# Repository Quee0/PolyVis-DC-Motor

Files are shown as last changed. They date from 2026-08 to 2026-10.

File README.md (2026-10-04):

# PolyVis DC Motor ⚡️

<p align="left">
  
  
  
</p>

<p align="center">
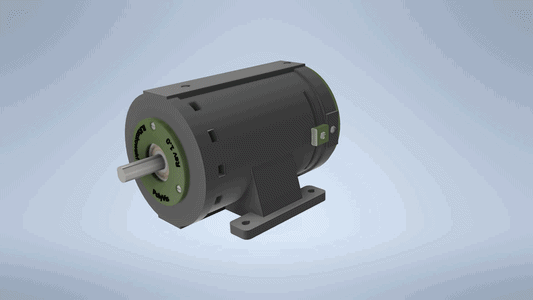
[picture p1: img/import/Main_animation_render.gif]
Podpis alternatywny
  
</p>

## 1. Project Overview

### 1.1 General Description

PolyVis is a fully functional, hybrid (3D-printed plastic + solid steel) brushed DC motor designed from scratch. The main goal was to create viable DC Motor, that can be built without expensive tools and hard-to-source materials. Furthermore its development was an R&D process bringing theoretical electromagnetism, Finite Element Analysis (FEA), and practical DIY manufacturing.

> [!NOTE]
> **This includes:**
>
> * Automated FEA methodology utilizing custom Python and Lua scripts for geometry generation and simulation,
> * Advanced parameters calculations using the Maxwell Stress Tensor to evaluate both electrodynamic and reluctance forces,
> * Real world characteristics reaserch,
> * Two-layer simplex lap winding integrated with a 6-segment commutator for smooth current switching,
> * Hybrid material architecture bridging the gap between accessible 3D printing and necessary ferromagnetic properties.

The end result is a fully functional prototype capable of validating theoretical models in the real world, demonstrating a practical understanding of electromagnetic design and applied physics.

### 1.2 Project & Idea Evolution

Initial assumptions involved building a brushed motor using easily available materials (3D printing, off-the-shelf parts). Method of estimating parameters, and whole project concept underwent a drastic and necessary transformation.

### 1.2.1 Material selection

#### ❌ All-Plastic Construction:

The original idea relied on 3D printing entire motor (except for the windings and magnets). It is quite common approch in DIY projects that demonstrates the working mechanism of brushed DC motor (or BLDC). This design was abandoned.

> [!NOTE]
> Plastic has a magnetic permeability close to that of a vacuum ( $\mu \approx \mu_0$ ). The lack of a ferromagnetic material in the magnetic circuit makes concentrating the magnetic flux impossible, which in practice means drastically low efficiency and negligible torque.

#### ✅ Hybrid Construction (Plastic + Solid Steel):

To solve the lack of a ferromagnetics, the concept evolved into a hybrid solution. The rotor would be a plastic skeleton with an embedded steel core, and the stator is based on a solid steel pipe. To generate a strong 2-pole field using standard components, a multi-segment architecture was adopted. One half of the inner circumference is lined with small magnets facing with their N pole, and the other half with their S pole.

> [!NOTE]
> Solid steel is exposed to eddy currents, which would melt whole construction. Because this engine would be limited by its hybrid approch, the change of magnetic field in stator (eddy currents) would be negligible. On the other hand, rotor must be laminated. This hybrid was a conscious compromise. The lower efficiency and losses of this construction were accepted. This is a trade-off allows for the fabrication of a prototype in a home workshop environment.

### 1.2.2 Evolution of the Computational Methodology

Determining the forces and torque required the creation of a reliable mathematical model. This model went through successive stages, discarding simplified assumptions in favor of a full electromagnetic simulation.

**1. Custom Python Script:**

* **Idea:** Custom simulation script of dipole distribution in a vacuum. The tool had immense educational value and developed physical intuition, but the script could not model the ferromagnetic material behaviour.
* **Verdict:** This solution was rejected as the primary design tool. Nonetheless this project is a great educational tool and an enormous help for visualising magnetic field in free space. Mathematics was derived and developed based on equations "Introduction to Electrodynamics" by David J. Griffiths - a foundational text in the field.
  *Note: The code was spun off into a standalone repository:* [`dipole-magnetostatic-solver`](https://github.com/Quee0/dipole-magnetostatic-solver).

**2. Classical Magnetic Circuit (Reluctance modeling):**

* **Idea:** Another approch to this problem was to solve a magnetic circuit. This method quickly ran into a problem with calculating reluctances of airgaps.
* **Verdict:** After reaserch, finding equations for different reluctances shapes and mailing a professor from my university suggested that this method cannot be precise. It failed due to a lack of reliable empirical data for the complex geometry.

#### Finite element analysis (FEMM & Lorentz Force):

* **Idea:** To be as precise as possible in this kind of project FEA method was chosen (via free FEMM software). Initial thought was to simulate wide range of geometries and then integrate forces acting solely on current-carrying conductors placed in the slots.
* **Verdict:** This method is used in standard electrodynamics courses, but it does not consider reluctance forces (lorenz force on ferromagnetics carrying the current). Upon further reaserch I choose to stick to FEMM software and develop results based on Maxwell stress tensor.

#### Final Model (FEA FEMM & Maxwell Stress Tensor):

* **Idea:** Utilizing the FEA environment (FEMM) to simulate the field distribution with full consideration of material non-linearities. Torque is determined directly using the Maxwell Stress Tensor.
* **Verdict:** Integrating stresses over a virtual contour (volume) surrounding the rotor allows for precise inclusion of both electrodynamic and reluctance forces in a single pass. It calculates forces based on fields nonsymmetry caused by the rotor. Theoretical derivation is in math chapter. In parallel with the magnetic verification, key electrical and topological parameters were established, forming the foundation for the commutator's construction:Topology: Simplex lap winding.

## 2. Simulation, Calculations & Geometry Selection

<p align="center">
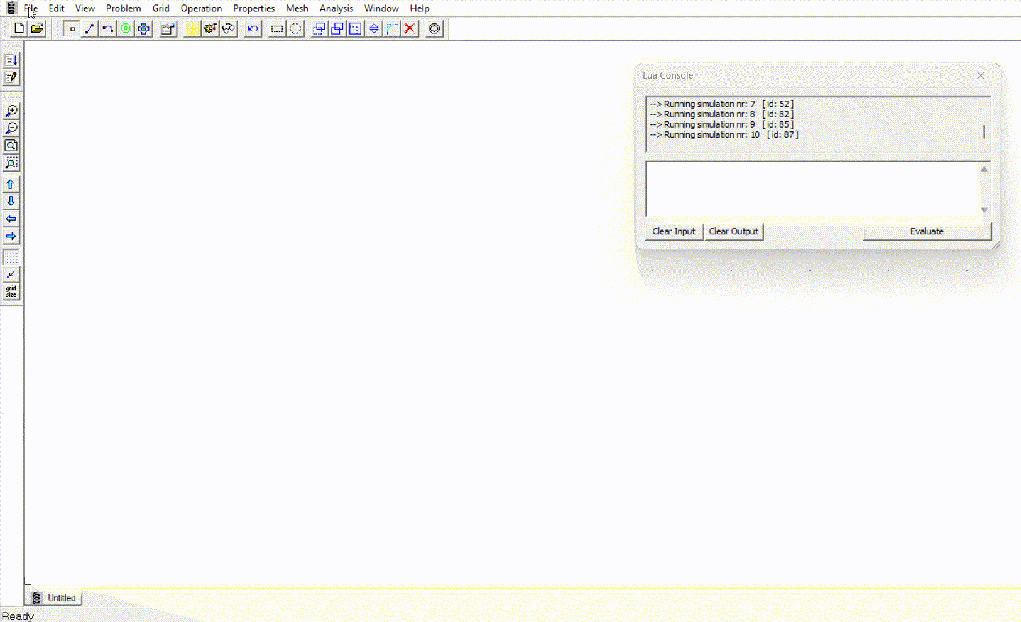
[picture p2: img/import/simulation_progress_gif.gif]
  
</p>

The current script model for geometry optimization and selection was developed on the open-source finite element analysis tool - FEMM (`www.femm.info`). The script generates and tests various geometries, then simulates them and writes the data to Excel. On this basis, it was possible to select the target geometry and manually correct the parameters.

### 2.1 Simulation Files

```
root-directory
├── ...
└── simulation_femm/
    ├── femm_handler_2nd_iteration.py
    ├── femm_handler.py
    ├── geometry_setup.lua
    └── output.csv
```

**2nd iteration arised after aknowleding parameter problems in the first one. You can change parameters in either of them.**

### 2.2 Running the Simulation

The simulation process has been fully automated using Python and Lua scripts. Python generates geometries and later opens FEMM with lua scripting. To run this script, you need to set up the appropriate working environment.

* **Install Python** (version 3.x).
* **Install FEMM 4.2** (Finite Element Method Magnetics).

> [!WARNING]
> **Critical path requirement:** The main Python script calls the simulation engine directly. During the FEMM installation, make sure the destination path is exactly (or change destination in script):
> `C:\femm42\bin\femm.exe`

The script utilizes external libraries for data handling and generating final result spreadsheets. Install them using the `pip` package manager:

```bash
pip install numpy pandas xlsxwriter
```

To begin the Monte Carlo simulation, open a terminal in the target folder and run the script:

```bash
python femm_handler_2nd_iteration.py
```

**Background execution process:**
Upon launch, the script will automatically generate the `femm_input.lua` parameter batch file and execute the FEMM engine. Each valid geometry will be simulated and temporarily saved to the `output.csv` file. Once all iterations are complete, the script will sort the data by the highest torque and export a clean spreadsheet named `Simulation_output.xlsx`.

### 2.3 Maxwell stress tensor derivation

Main calculation done directly in FEMM is torque on rotor. I used volumetric integral (surface integral in 2D) of Maxwell's stress tensor. Typical academical approach to electromagnetic problems is to treat them as tranciver and reciver. One object generates electromagnetic field and the other expirience force. Based on my reaserch this approach is insufficient. It cannot easily determine forces on ferromagnetic elements (reluctance forces). Alternative approach is derived based on assimetry of electromagnetic field. It evaluates both the electrodynamic forces acting on the coils and the reluctance forces exerted on the ferromagnetic components. While the Virtual Work method provides a viable alternative for capturing reluctance forces through magnetic energy variations, the Maxwell stress tensor was selected for its direct and computationally efficient integration along the bounding surface.

#### Stress tensor derivation:

<details>
<summary><b> Expand for further details </b></summary>

Total electromagnetic force:

$$\mathbf{F} = q(\mathbf{E} + \mathbf{v} \times \mathbf{B}) = \int\int\int (\mathbf{E} + \mathbf{v} \times \mathbf{B})\rho dV$$

The force per unit volume is:

$$\mathbf{f} = \rho\mathbf{E} + \mathbf{J} \times \mathbf{B}$$

Next, charge density $\rho$ and current density $\mathbf{J}$ can be expressed in terms of fields $\mathbf{E}$ and $\mathbf{B}$, using Gauss's law and Ampère's law:

$$\mathbf{f} = \varepsilon_0 (\nabla \cdot \mathbf{E}) \mathbf{E} + \frac{1}{\mu_0} (\nabla \times \mathbf{B}) \times \mathbf{B} - \varepsilon_0 \frac{\partial \mathbf{E}}{\partial t} \times \mathbf{B}$$

Another transformation comes from rewriting the Poynting vector. Using the product rule and Faraday's law of gives:

$$\frac{\partial}{\partial t} (\mathbf{E} \times \mathbf{B}) = \frac{\partial \mathbf{E}}{\partial t} \times \mathbf{B} + \mathbf{E} \times \frac{\partial \mathbf{B}}{\partial t} = \frac{\partial \mathbf{E}}{\partial t} \times \mathbf{B} - \mathbf{E} \times (\nabla \times \mathbf{E})$$

And now $\mathbf{f}$ as:

$$\mathbf{f} = \varepsilon_0 (\nabla \cdot \mathbf{E}) \mathbf{E} + \frac{1}{\mu_0} (\nabla \times \mathbf{B}) \times \mathbf{B} - \varepsilon_0 \frac{\partial}{\partial t} (\mathbf{E} \times \mathbf{B}) - \varepsilon_0 \mathbf{E} \times (\nabla \times \mathbf{E})$$

Rearrange $\mathbf{E}$ and $\mathbf{B}$:

$$\mathbf{f} = \varepsilon_0 \left[ (\nabla \cdot \mathbf{E}) \mathbf{E} - \mathbf{E} \times (\nabla \times \mathbf{E}) \right] + \frac{1}{\mu_0} \left[ -\mathbf{B} \times (\nabla \times \mathbf{B}) \right] - \varepsilon_0 \frac{\partial}{\partial t} (\mathbf{E} \times \mathbf{B})$$

"Fixing" symmetry by inserting $0 = (\nabla \cdot \mathbf{B}) \mathbf{B}$:

$$\mathbf{f} = \varepsilon_0 \left[ (\nabla \cdot \mathbf{E}) \mathbf{E} - \mathbf{E} \times (\nabla \times \mathbf{E}) \right] + \frac{1}{\mu_0} \left[ (\nabla \cdot \mathbf{B}) \mathbf{B} - \mathbf{B} \times (\nabla \times \mathbf{B}) \right] - \varepsilon_0 \frac{\partial}{\partial t} (\mathbf{E} \times \mathbf{B})$$

Eliminating the crossproducts (which are complicated to calculate), using the vector calculus identity:

$$\frac{1}{2} \nabla (\mathbf{A} \cdot \mathbf{A}) = \mathbf{A} \times (\nabla \times \mathbf{A}) + (\mathbf{A} \cdot \nabla) \mathbf{A} ,$$

leads to:

$$\mathbf{f} = \varepsilon_0 \left[ (\nabla \cdot \mathbf{E}) \mathbf{E} + (\mathbf{E} \cdot \nabla) \mathbf{E} \right] + \frac{1}{\mu_0} \left[ (\nabla \cdot \mathbf{B}) \mathbf{B} + (\mathbf{B} \cdot \nabla) \mathbf{B} \right] - \frac{1}{2} \nabla \left( \varepsilon_0 E^2 + \frac{1}{\mu_0} B^2 \right) - \varepsilon_0 \frac{\partial}{\partial t} (\mathbf{E} \times \mathbf{B}) .$$

This expression contains every aspect of electromagnetism and momentum and is relatively easy to compute. It can be written more compactly by introducing the **Maxwell stress tensor**,

$$\sigma_{ij} = \varepsilon_0 \left( E_i E_j - \frac{1}{2} \delta_{ij} E^2 \right) + \frac{1}{\mu_0} \left( B_i B_j - \frac{1}{2} \delta_{ij} B^2 \right) .$$

All but the last term of $\mathbf{f}$ can be written as the tensor divergence of the Maxwell stress tensor, giving:

$$\nabla \cdot \boldsymbol{\sigma} = \mathbf{f} + \varepsilon_0 \mu_0 \frac{\partial \mathbf{S}}{\partial t} ,$$

In FEMM we analise magnetostatic problem, so time derivative of Poynting vector is always 0, so:

$$\mathbf{f} = \nabla \cdot \boldsymbol{\sigma},$$

We integrate force per unit volume to get total force enduced on volume:

$$F = \int\int\int \mathbf{f} dV = \int\int\int \nabla \cdot \boldsymbol{\sigma} dV,$$

And finally we use the divergance theorem to get rid of nabla and replace integral type:

$$F = \int\int \boldsymbol{\sigma} \cdot dS$$

(Complete derivation: https://en.wikipedia.org/wiki/Maxwell_stress_tensor)

</details>

### 2.4 Motor parameters calculation model

<p align="center">
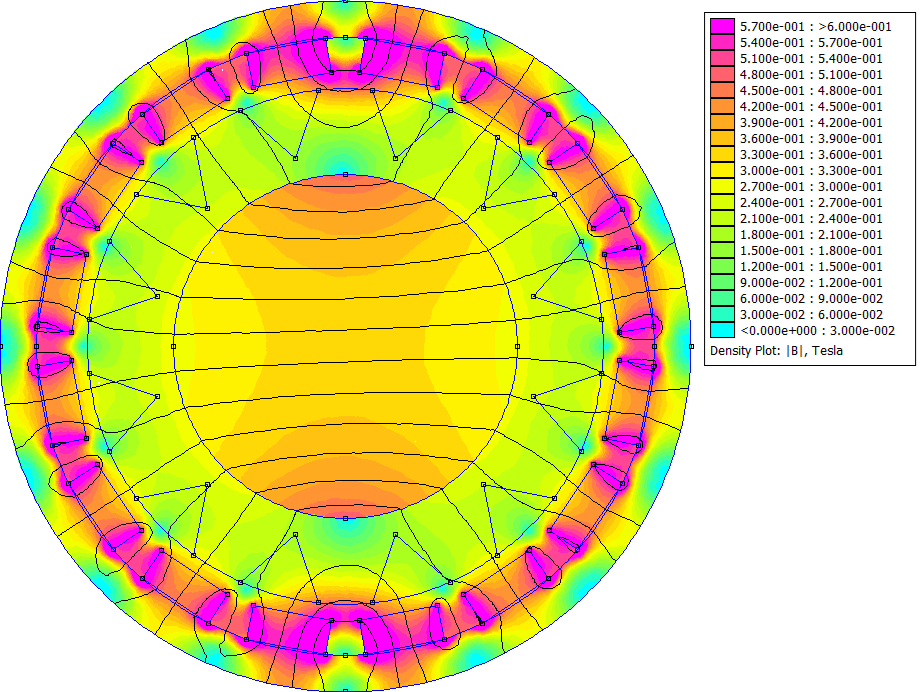
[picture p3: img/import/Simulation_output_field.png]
  
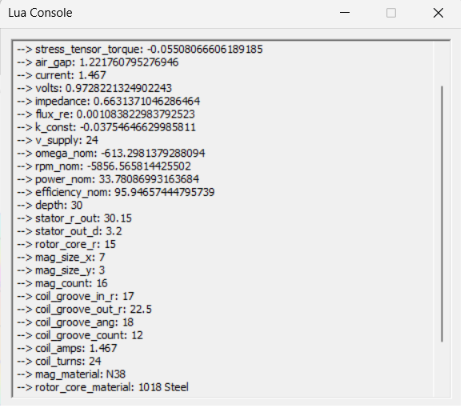
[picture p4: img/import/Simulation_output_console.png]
  
</p>

Apart from defined and read parameters, python & lua scripts calculate and evaluate more expected values.

* **Torque Constant ($k_{const}$):** Determined as total electromagnetic torque (calculated using the Maxwell Stress Tensor) devided by the current flowing through the winding.

$$k_{const} = \frac{T}{I}$$

* **Back EMF:** The script calculates the voltage drop across the windings, incorporating a correction factor of $1.45$. The electromotive force is the difference between the defined supply voltage ($V_{supply} = 24\text{ V}$) and this voltage drop.

$$EMF = V_{supply} - (I \cdot Z)$$

* **Rotational Speed ($\omega$):** The angular velocity ($\omega$) in radians per second is the Back-EMF devided by the torque constant.

$$\omega = \frac{EMF}{k_{const}}$$

It can be later recalculated into RPM:

$$RPM = \omega \cdot \frac{30}{\pi}$$

* **Energy Efficiency ($\eta$):** Defined as the ratio of useful mechanical power to the total electrical power consumed. In non ideal reality efficienty is lower, because of work done by resistance forces. Despite that, this calculation allowed to compare different geometries.

$$\eta = \frac{\omega \cdot T}{V_{supply} \cdot I} \cdot 100\%$$

---

<details>
<summary><b> Verification of the output parameters: </b></summary>

* Electromagnetic torque ($T$): $-0.055\text{ Nm}$
* Current ($I$): $1.47\text{ A}$
* Voltage drop ($V_{drop}$): $0.973\text{ V}$
* Supply voltage ($V_{supply}$): $24\text{ V}$
* **Torque constant ($k_t$):**

$$k_const = \frac{-0.055}{1.467} = -0.0375$$

* **Nominal angular velocity ($\omega$):**

$$\omega = \frac{24 - 0.973}{-0.0375} = -613.3 \text{ rad/s}$$

* **Rotational speed (RPM):**

$$RPM = -613.3 \cdot \frac{30}{\pi} = -5856.6$$

* **Useful mechanical power ($P_{mech}$):**

$$P_{mech} = -613.3 \cdot (-0.055) = 33.8 \text{ W}$$

* **Total efficiency ($\eta$):**

$$\eta = \frac{33.8}{24 \cdot 1.467} \cdot 100 = 95.95 \%$$

</details>

### 2.5 Winding schamatic

This construction utilizes a two-layer simplex lap winding. It is integrated with a 12-slot core and a 6-segment commutator. The winding process begins at `Plate 1` which, at the illustrated commutation moment, serves as the positive voltage application point. The wire forms the first coil (L1) spanning from slot 1 to 7, and then directly proceeds to form the second coil (L2) routed through slots 2 to 8. This dual series sequence terminates at `Plate 2`. This configuration is replicated symmetrically around the entire commutator. The topology completes its loop by physically connecting the output of the final coil L12 (12-6) back to the initial `Plate 1`. After `Plate 4`, coils are wound as a second layer. It allows for the utilization of all plates while maintaining one-way current flow within each slot. Positioning the opposite power terminal (GND) on `Plate 4` effectively divides this closed circuit into two symmetrical, parallel current branches.

<p align="center">
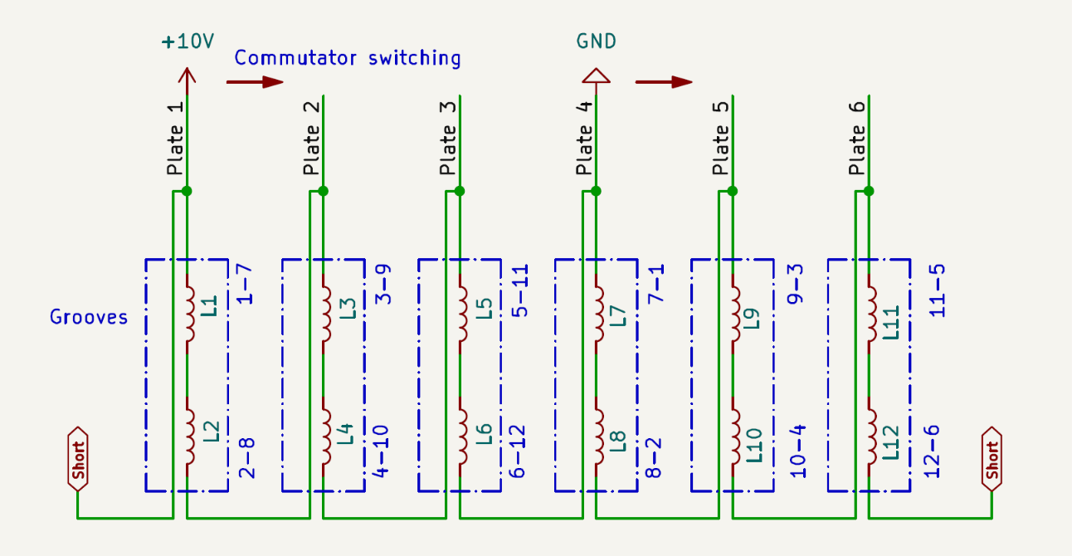
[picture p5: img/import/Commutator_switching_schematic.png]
  
</p>

## 3. Physical Build

### 3.X Motor Performance Characteristics

To fully validate the physical build motor, its real-world performance is mapped against standard brushed DC motor characteristic curves. These idealized curves illustrate how the machine's primary parameters behave as the mechanical load (Torque) on the shaft increases from a free-spinning state (No-Load) to a complete stop (Stall).

<p align="center">
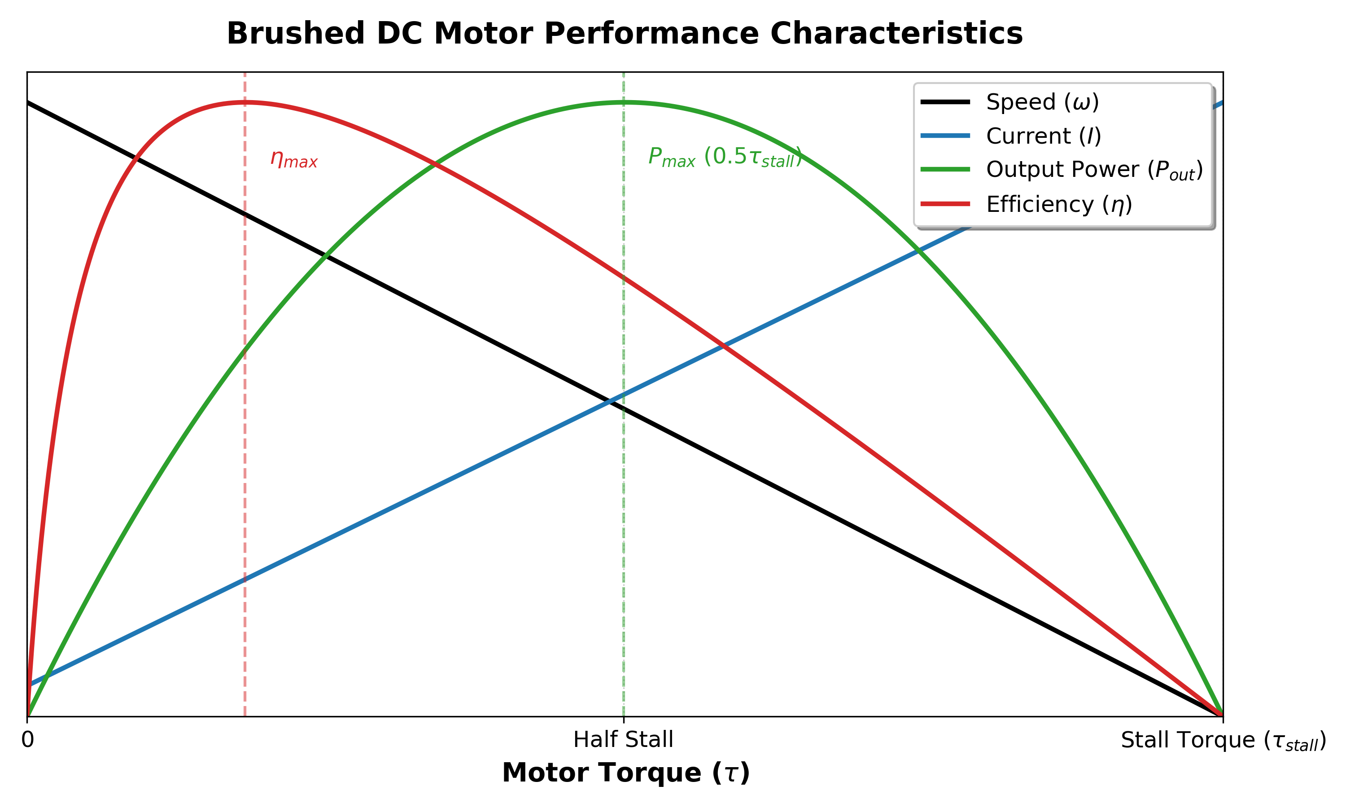
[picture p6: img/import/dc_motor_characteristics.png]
  
</p>

* **Rotational Speed ($\omega$):** Exhibits a linear decline as torque increases. The motor operates at its highest velocity under no load ($n_0$) and linearly drops to zero when the load exceeds the motor's capacity (Stall Torque).
* **Current Draw ($I$):** Shows a direct, linear increase proportional to the applied torque. It begins at a minimal no-load current (the energy required to overcome internal mechanical friction and magnetic losses) and reaches its absolute peak at stall condition.
* **Mechanical Output Power ($P_{out}$):** Forms a classic parabolic curve. Since mechanical power is the product of angular speed and torque ($P = \omega \cdot \tau$), it equals zero at both extremes (no torque and no speed). The maximum output power ($P_{2max}$) is theoretically achieved exactly at 50% of the stall torque and 50% of the no-load speed.
* **Efficiency ($\eta$):** Represents the ratio of useful mechanical power output to the electrical power input. The efficiency rises sharply to its maximum peak ($\eta_{max}$) at relatively low torque values (typically around 10-20% of the stall torque, often denoted as roughly $1/7 M_h$). Beyond this optimal point, as current (and resistive $I^2R$ heating) increases drastically, efficiency gradually drops to zero at the stall point.

## 4. CAD

## 5. Bill of materials

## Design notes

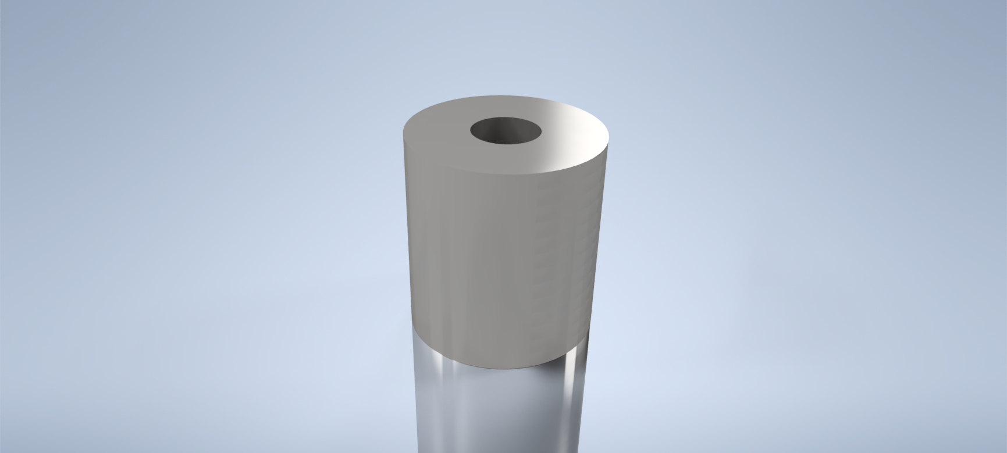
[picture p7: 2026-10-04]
model/renders/rotor_core.png

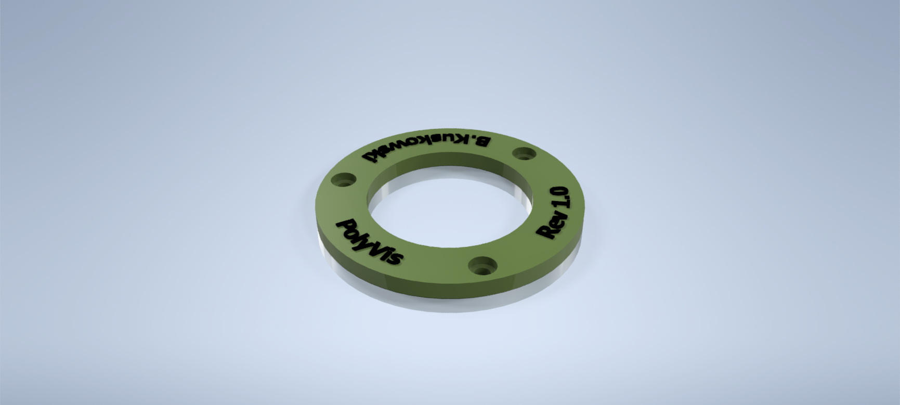
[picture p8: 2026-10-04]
model/renders/name_plate.png

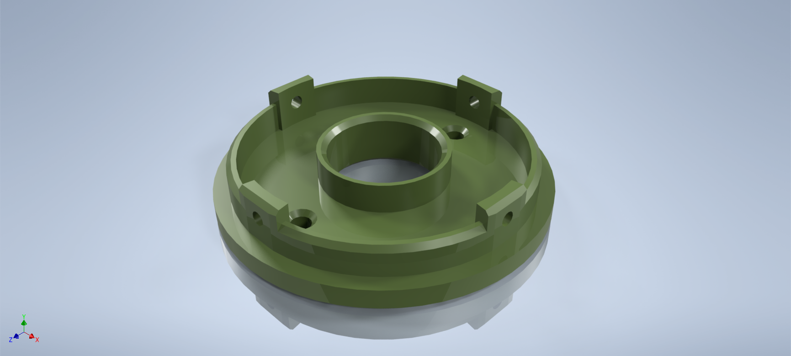
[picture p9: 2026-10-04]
model/renders/back_sleeve.png

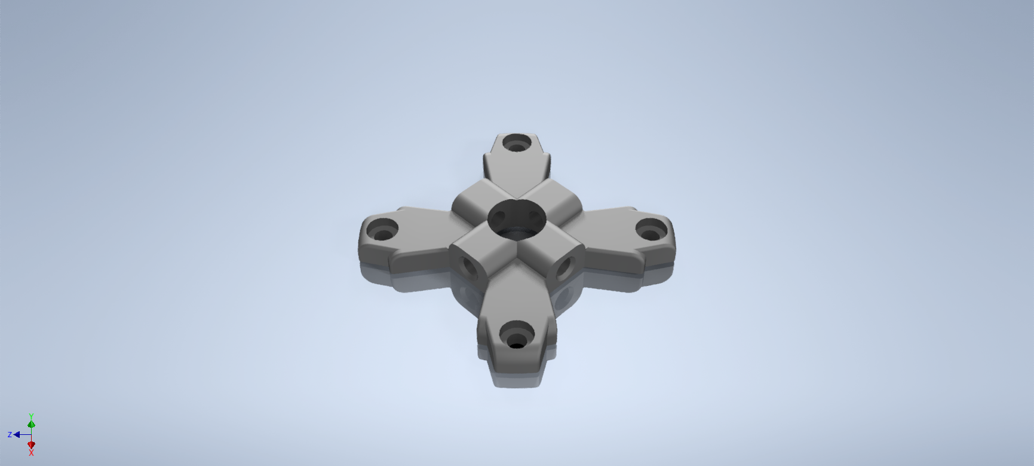
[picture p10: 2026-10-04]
model/renders/shaft_lock.png

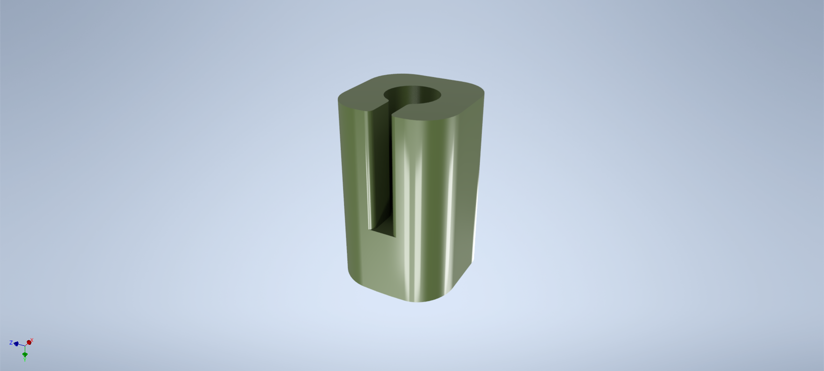
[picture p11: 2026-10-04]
model/renders/brush_holder_batt.png

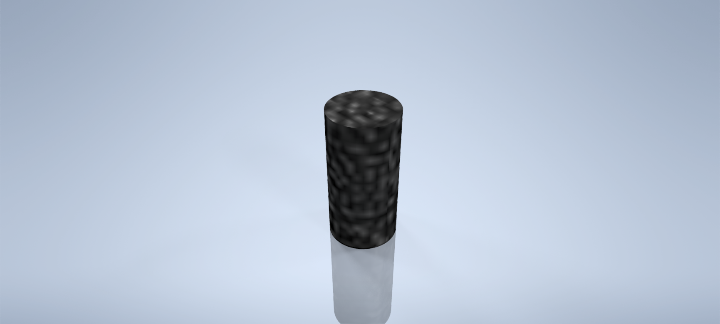
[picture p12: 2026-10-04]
model/renders/carbon_brush_batt.png

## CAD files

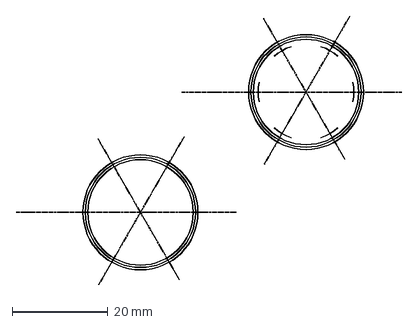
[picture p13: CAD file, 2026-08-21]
model/parts/commutator_plate_cut.dxf
80.4 x 56.0 mm

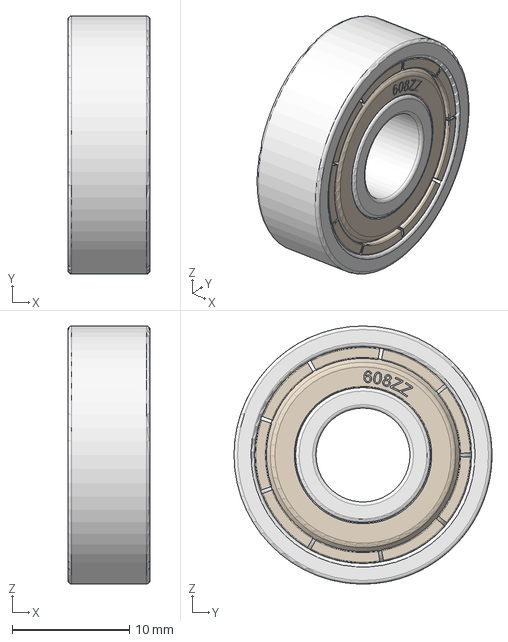
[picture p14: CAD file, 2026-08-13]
model/parts/import/608zz.step
7.00 x 22.0 x 22.0 mm

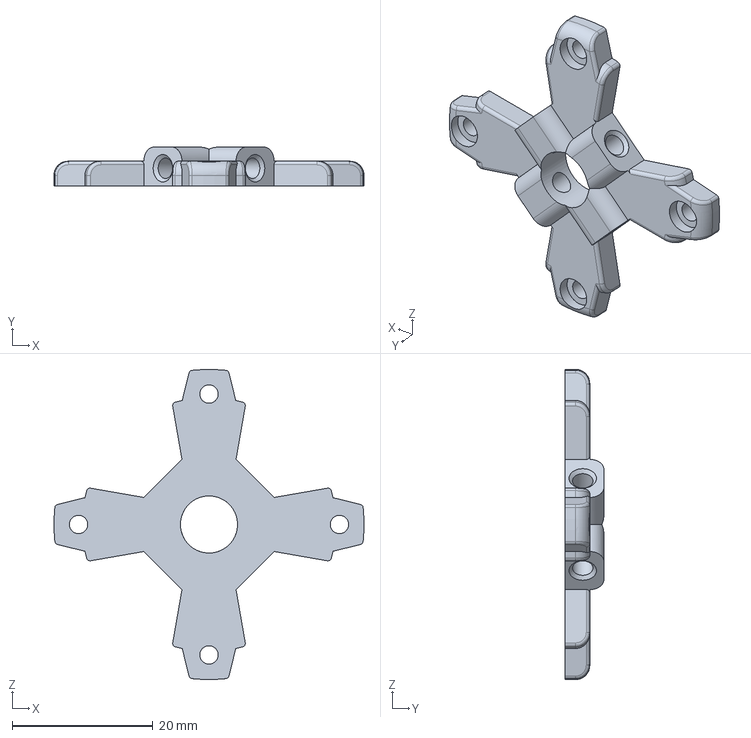
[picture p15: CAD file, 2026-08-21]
model/prints/shaft_lock_1.stp
44.0 x 5.50 x 44.0 mm

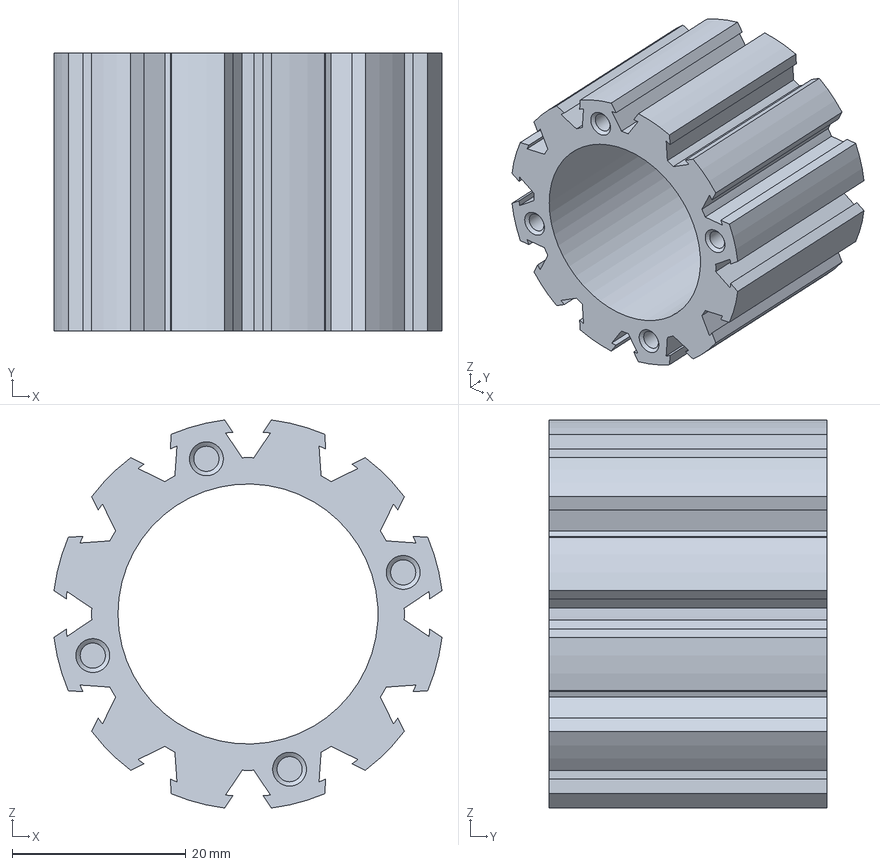
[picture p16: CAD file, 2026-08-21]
model/prints/rotor_plastic.stp
44.7 x 32.0 x 44.7 mm

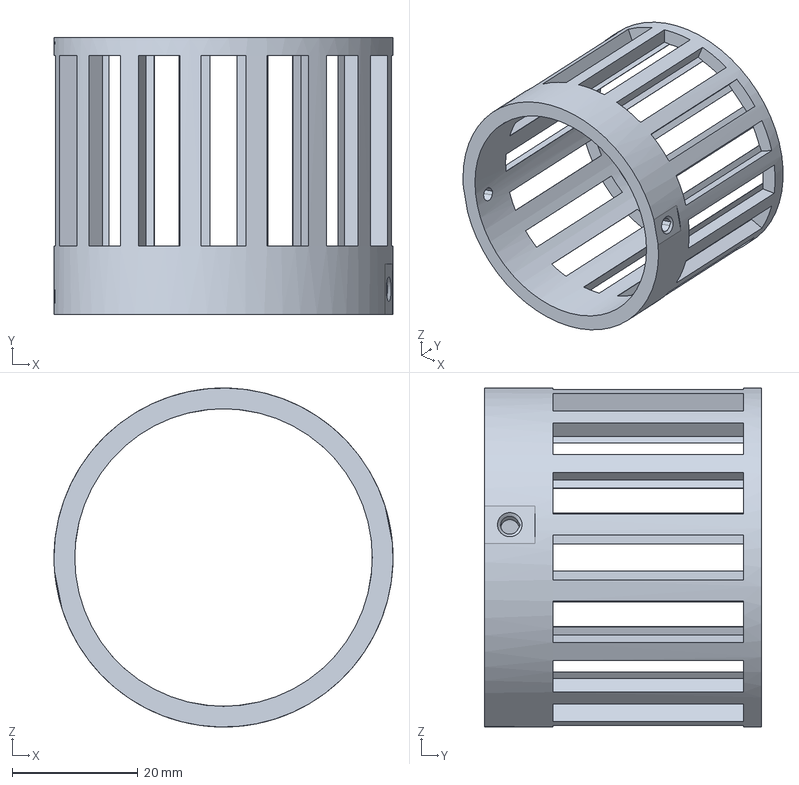
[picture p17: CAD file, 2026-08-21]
model/prints/magnet_ring.stp
53.9 x 44.0 x 53.9 mm

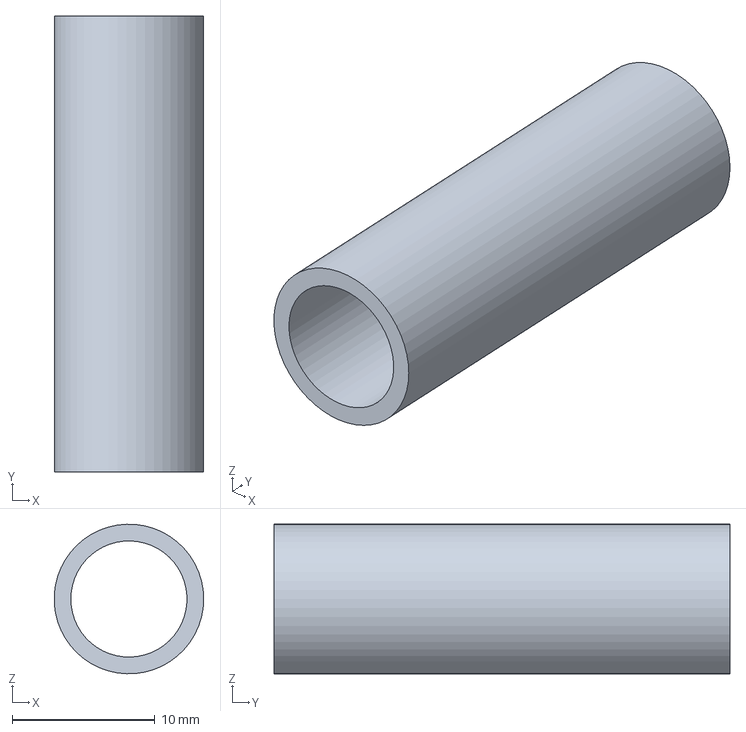
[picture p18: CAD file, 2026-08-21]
model/prints/rotor_sleeve.stp
10.5 x 32.0 x 10.5 mm

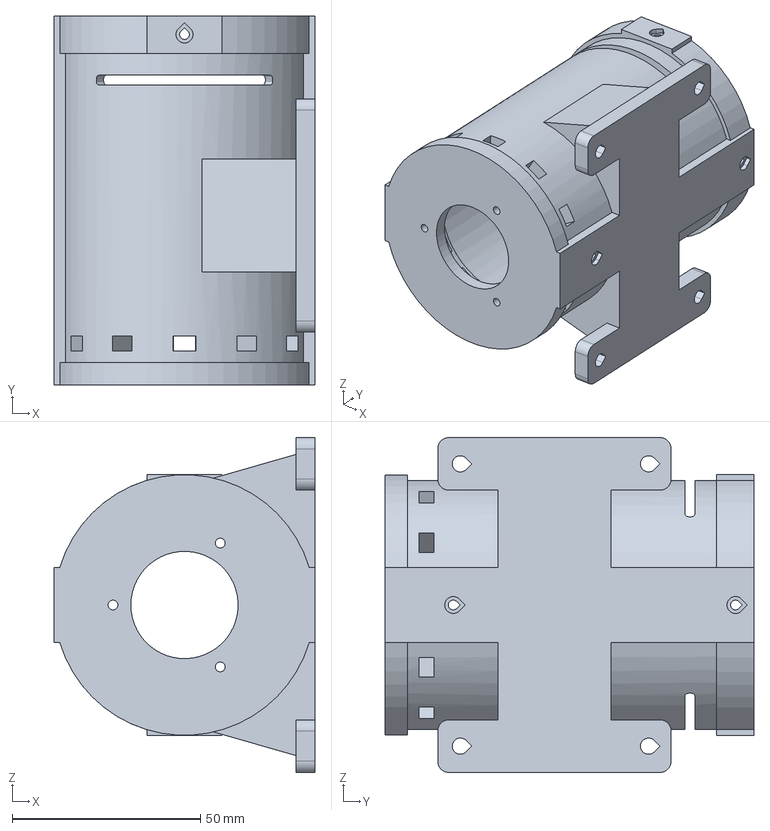
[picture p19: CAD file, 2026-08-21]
model/prints/casing_cylindrical.stp
69.2 x 98.0 x 89.0 mm

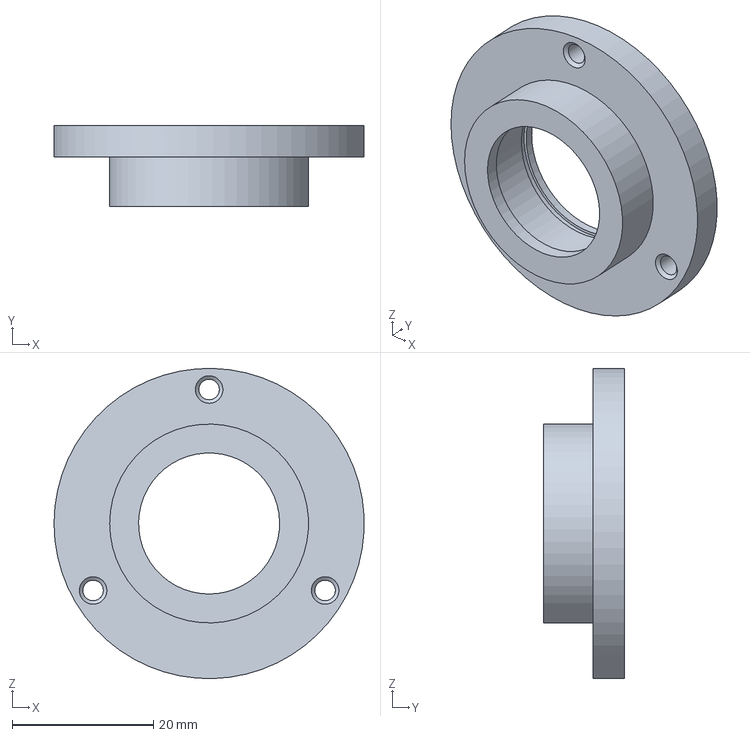
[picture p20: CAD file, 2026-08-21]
model/prints/sleeve.stp
44.0 x 11.5 x 44.0 mm

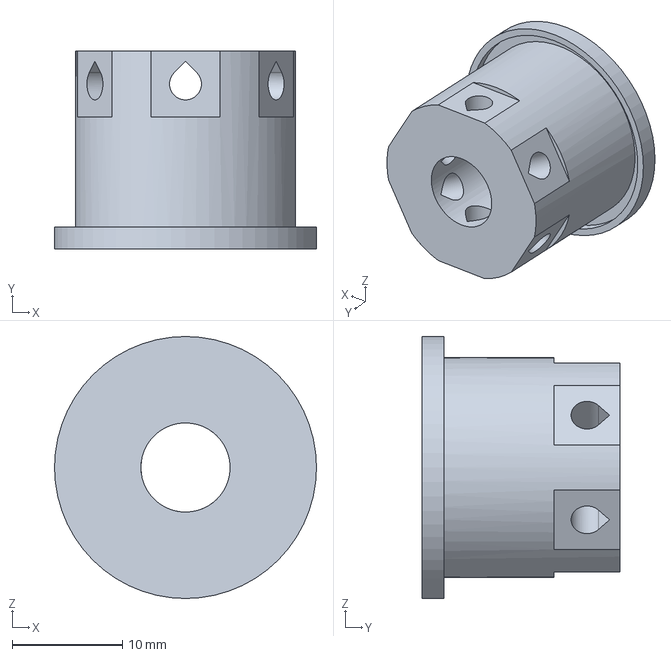
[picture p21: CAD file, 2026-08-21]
model/prints/commutator_plastic.stp
23.8 x 18.0 x 23.8 mm

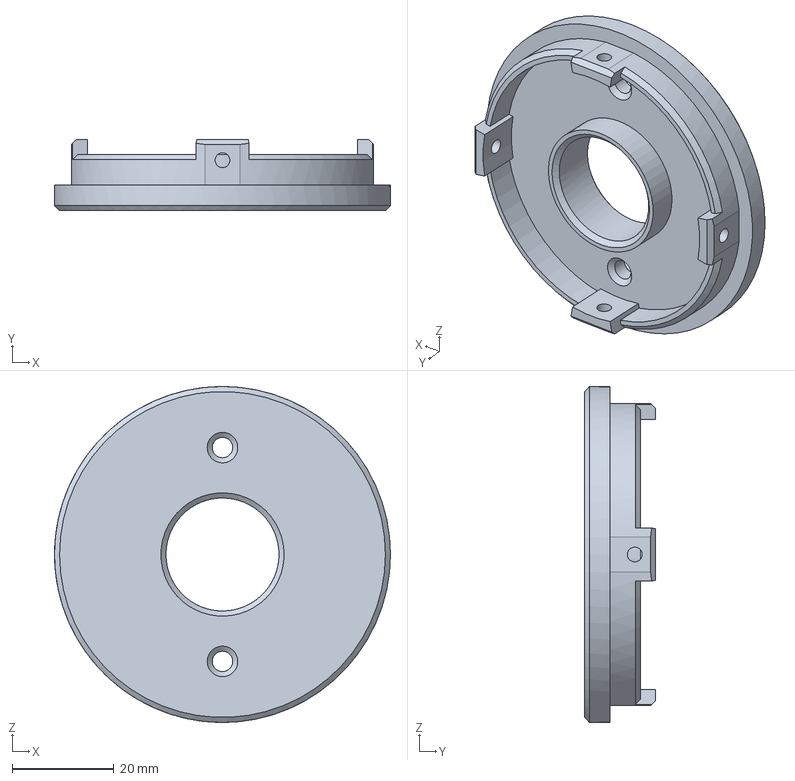
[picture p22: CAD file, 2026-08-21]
model/prints/back_sleeve.stp
66.0 x 14.0 x 66.0 mm

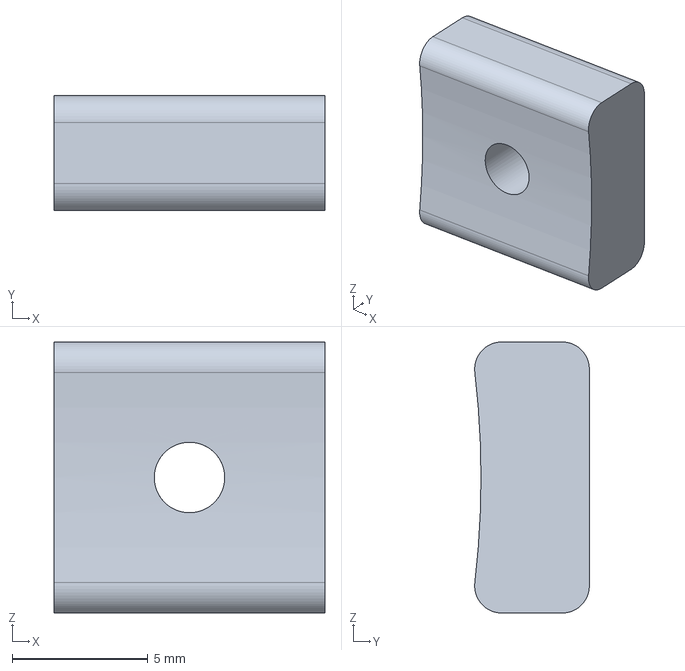
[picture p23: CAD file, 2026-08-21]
model/prints/brush_cart_outer_holder.stp
10.0 x 4.24 x 10.0 mm

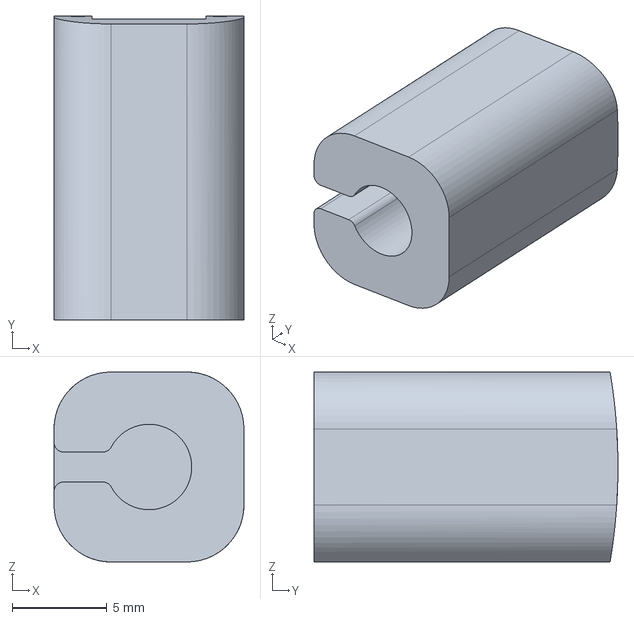
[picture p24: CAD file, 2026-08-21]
model/prints/brush_holder_batt.stp
10.0 x 16.0 x 10.0 mm

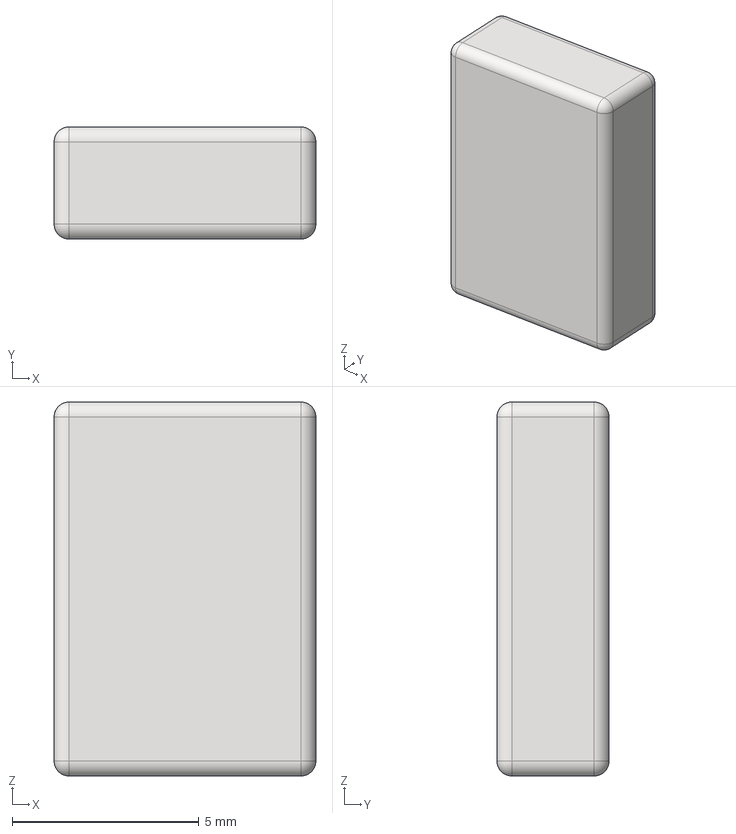
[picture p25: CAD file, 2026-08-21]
model/prints/stator_magnet_tester.stp
7.00 x 3.00 x 10.0 mm

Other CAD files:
model/prints/template.3mf
model/prints/shaft_lock_2.stp
model/assemblies/commutator_assembly.iam
model/assemblies/magnet_ring_assembly.iam
model/assemblies/main_assembly.iam
model/assemblies/main_assembly_presentation.ipn
model/assemblies/rotor_core.iam
model/parts/608zz.ipt
model/parts/back_sleeve.ipt
model/parts/brush_cart_outer_holder.ipt
model/parts/brush_cart_outer_holder_MIR.ipt
model/parts/brush_holder_batt.ipt
model/parts/brush_holder_batt_MIR.ipt
model/parts/brush_spring.ipt
model/parts/carbon_brush_batt.ipt
model/parts/carbon_brush_batt_MIR.ipt
model/parts/casing_cylindrical.ipt
model/parts/commutator_plastic.ipt
model/parts/commutator_plate.ipt
model/parts/magnet_ring.ipt
model/parts/name_plate.ipt
model/parts/rotor_plastic.ipt
model/parts/rotor_sleeve.ipt
model/parts/shaft.ipt
model/parts/shaft_lock_1.ipt
model/parts/shaft_lock_2.ipt
model/parts/single_coil.ipt
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

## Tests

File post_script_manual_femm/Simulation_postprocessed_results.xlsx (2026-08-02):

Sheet: Results
session_id | stress_tensor_torque | air_gap | current | volts | impedance | flux_re | k_const | v_supply | omega_nom | rpm_nom | power_nom | efficiency_nom | depth | stator_r_out | stator_out_d | rotor_core_r | mag_size_x | mag_size_y | mag_count | coil_groove_in_r | coil_groove_out_r | coil_groove_ang | coil_groove_count | coil_amps | coil_turns | mag_material | rotor_core_material | stator_material | plastic_material | coil_material
107521 | -0.007966703494 | 0.7803887662 | 1.23 | 0.1687404751 | 0.1371873781 | 0.0005774746132 | -0.006476994711 | 24 | -3679.369922 | -35135.39463 | 29.31244922 | 99.29691469 | 1 | 30 | 2 | 10 | 7 | 4 | 10 | 12 | 23 | 20 | 10 | 1.23 | 163 | N52 | 1018 Steel | 1018 Steel | Air | 24 AWG
29832 | -0.006162410426 | 0.83281573 | 1.23 | 0.2231929229 | 0.1814576609 | 0.000828573448 | -0.005010089778 | 24 | -4745.784633 | -45318.90499 | 29.2454727 | 99.07002949 | 1 | 30 | 3 | 7.5 | 6 | 4 | 12 | 11 | 22 | 20 | 14 | 1.23 | 154 | N52 | 1018 Steel | 1018 Steel | Air | 24 AWG
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

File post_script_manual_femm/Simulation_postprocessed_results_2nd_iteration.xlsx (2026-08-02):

session_id | stress_tensor_torque | air_gap | current | volts | impedance | flux_re | k_const | v_supply | omega_nom | rpm_nom | power_nom | efficiency_nom | depth | stator_r_out | stator_out_d | rotor_core_r | mag_size_x | mag_size_y | mag_count | coil_groove_in_r | coil_groove_out_r | coil_groove_ang | coil_groove_count | coil_amps | coil_turns | mag_material | rotor_core_material | stator_material | plastic_material | coil_material
86240 | -0.3726501596 | 0.6487347016 | 1.467 | 4.177280222 | 2.847498447 | 0.01171552516 | -0.254021922 | 24 | -78.03546884 | -745.1838361 | 29.07992991 | 82.59466574 | 50 | 30 | 1 | 16 | 9 | 4 | 14 | 18 | 24 | 16 | 14 | 1.467 | 53 | N38 | 1018 Steel | 1018 Steel | Air | 22 AWG
434558 | -0.370080763 | 0.788018341 | 0.9225 | 7.565370504 | 8.200943636 | 0.024029917 | -0.4011715588 | 24 | -40.96658683 | -391.2020877 | 15.16094571 | 68.4776229 | 50 | 30 | 1 | 16 | 7 | 4 | 14 | 18 | 24 | 18 | 14 | 0.9225 | 96 | N38 | 1018 Steel | 1018 Steel | Air | 24 AWG
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

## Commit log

2026-07-14 Basic geometry material assignment
2026-07-16 full geometry, windings and torque check, fixes #3
2026-07-20 Fixed rotor and stator set angle
2026-08-02 Iterations, validations and root geometry development
    [Simulation_postprocessed_results.xlsx, Simulation_postprocessed_results_2nd_iteration.xlsx]
2026-08-04 Started model creation
    [casing_cylindrical.ipt, magnet_ring.ipt, magnet_ring_assembly.iam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]
2026-08-07 Proper shaft locks
    [casing_cylindrical.ipt, comutator_plastic.ipt, magnet_ring.ipt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]
2026-08-13 Added commutator, conctruction development
    [608zz.ipt, 608zz.step, carbon_brush_batt.ipt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]
2026-08-21 almost Rev 1.0, full 3d print files
    [back_sleeve.ipt, back_sleeve.stp, brush_cart_outer_holder.ipt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]
2026-08-30 Full inventor assembly v1.0
    [back_sleeve.ipt, brush_cart_outer_holder.ipt, brush_holder_batt.ipt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]
2026-09-25 Further readme updates fixes #13, fixes #8
    [main_assembly.iam]
2026-09-29 CAD animation added, fixes #17
    [main_assembly.iam, main_assembly_presentation.ipn, name_plate.ipt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]
2026-10-04 Renders and readme updates, fixes #16
    [brush_cart_outer_holder.ipt, brush_holder_batt.ipt, brush_spring.ipt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]
2026-10-12 print elements section added
